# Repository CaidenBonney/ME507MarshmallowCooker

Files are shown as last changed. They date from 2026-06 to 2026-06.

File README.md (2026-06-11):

# ME507 Marshmallow Cooker

## Overview

The ME507 Marshmallow Cooker is an automated system designed to cook the perfect marshmallow for s'mores! The marshmallow cooker roasts the marshmallows to a desired temperature using sensor feedback and motorized positioning.

The system is based on an STM32F411 microcontroller and incorporates both contact and non-contact temperature sensing. The rotating mechanism (rotisserie) ensures an even cook while the vertical positioning system modulates the distance between the marshmallow and the heat source (demoing with a Sterno).

## Team Members

* Caiden Bonney
* Toby Sagi

## Hardware

### Sensors

* MLX90614 infrared temperature sensor
* MCP9600 thermocouple amplifier with Type T thermocouple
* Top and bottom Z-axis limit switches

### Actuators

* Pololu 5120 gearmotor with quadrature encoder and DRV8833 brushed DC motor driver
* DF Robot Fit0278 stepper motor with TMC2209 stepper motor driver

### Custom Electronics

* Custom PCB designed for STM32, sensor integration, and motor control.

## Firmware Architecture

The firmware is written primarily in C++ using STM32CubeIDE and STM32 HAL.

Major drivers include:

* Task_UI
* Task_Temps
* Task_R_Motor
* Task_Z_Motor
* MCP9600 thermocouple driver
* MLX90614 infrared temperature driver
* Encoder driver
* DRV8833 motor driver
* Rotational motor driver
* Z-axis limit switch driver
* Z-axis motor driver

## Documentation

Project documentation:

[ME507 Marshmallow Cooker Documentation](https://caidenbonney.github.io/ME507MarshmallowCooker/)

## Repository Structure

```text
ME507MarshmallowCooker
├── CAD
├── docs
├── Fusion
├── Marshmallow_Cooker
│   ├── Core
│   └── Drivers
├── Doxyfile
└── README
```

## Building the Project

1. Open `Marshmallow_Cooker` in STM32CubeIDE.
2. Build the project.
3. Flash the firmware to the STM32F411 target.
4. Open a serial terminal at 115200 baud for debugging output.

## License

This repository was created as part of the ME507 Mechatronics course at California Polytechnic State University.

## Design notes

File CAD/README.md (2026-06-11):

# CAD Files

This directory contains the mechanical CAD models, assemblies, and supporting design files used in the ME507 Marshmallow Cooker project.

## Contents

* Assembly file for the complete marshmallow cooker
* Individual part models
* Hardware: screws, nuts, etc.

## Software

The CAD models were created using SolidWorks.

## Purpose

These files document the mechanical design of the marshmallow cooker, including the rotating marshmallow assembly, vertical positioning mechanism, sensor mounting features, and overall system structure.

The CAD models were used for design iteration, interference checking, fabrication, and project documentation.

## Related Documentation

Additional renders and screenshots generated from these CAD models are included in the project documentation website.

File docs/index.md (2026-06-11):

@mainpage ME507 Marshmallow Cooker

# Project Overview

The ME507 Marshmallow Cooker is an automated marshmallow roasting system designed to cook the perfect marshmallow for s'mores. Using sensor feedback and motorized positioning, the system monitors temperature and automatically adjusts the marshmallow's position and orientation to achieve a consistent, repeatable roast.

<p align="center">
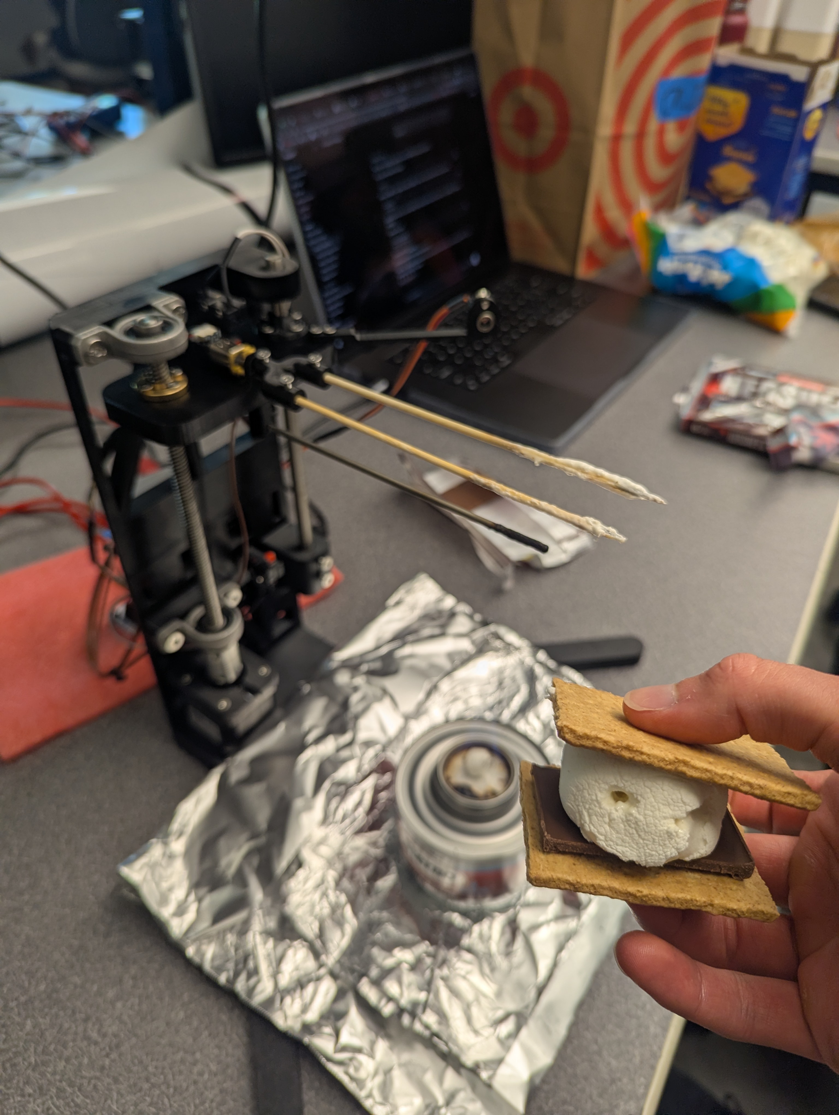
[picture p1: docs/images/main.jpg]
  
</p>

The system is based on an STM32F411 microcontroller and uses both infrared and thermocouple-based temperature measurements to monitor cooking conditions. A rotating mechanism (rotisserie) ensures an even cook, while a vertical positioning system adjusts the distance between the marshmallow and the heat source (demonstrated using a Sterno) to regulate roasting temperature. This combination of sensor feedback and motorized positioning allows the marshmallow to be cooked consistently to a desired temperature.

## Video Demonstration

[Click here to watch the Marshmallow Cooker in action!](https://cpslo-my.sharepoint.com/:v:/g/personal/clbonney_calpoly_edu/IQBmmSWm59pES4WM_rZA4jZBAax7FDM9BySxYHA97Abe1Qw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)

---

# Major Hardware

## BOM

Here is a link to our [Bill of Materials](https://cpslo-my.sharepoint.com/:x:/g/personal/clbonney_calpoly_edu/IQCO9qkZxfa1SrjVX5YEZTvCAYXNW5hFe5g4LbXm4rrSlMY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) (does not include CAD components)

## Rotating Motor Assembly

The rotating axis uses a Pololu 5120 gearmotor with integrated quadrature encoder. The 297.92:1, 45 rpm max motor provides slow, yet steady rotation of the marshmallow. A DRV8833 motor driver at 5V allows bidirectional PWM control from the STM32 microcontroller. A simple software driver was implemented to abstract direction control and PWM duty cycle commands.

<p align="center">
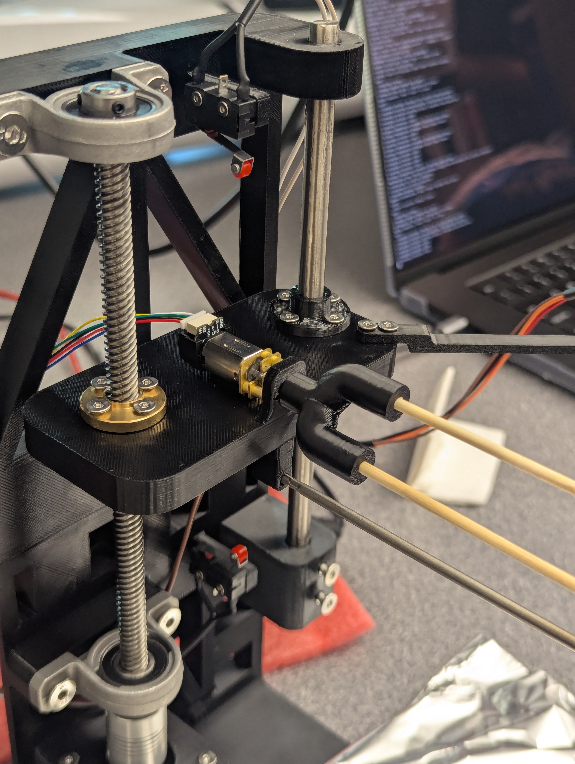
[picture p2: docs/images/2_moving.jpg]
  
</p>

The 12 CPR quadrature encoder provides position feedback that allows the software to estimate angular position and rotational velocity. Hardware timers count the encoder ticks, measuring the angular displacement of the motor.

<p align="center">
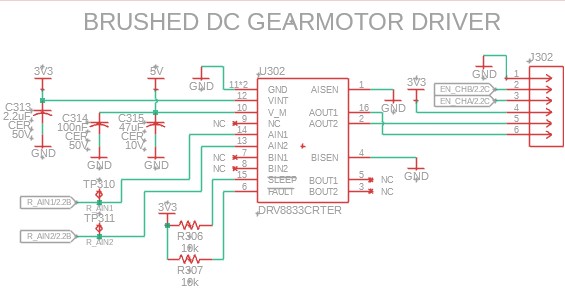
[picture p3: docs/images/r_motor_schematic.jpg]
  
</p>

## Vertical Motion System

<p align="center">
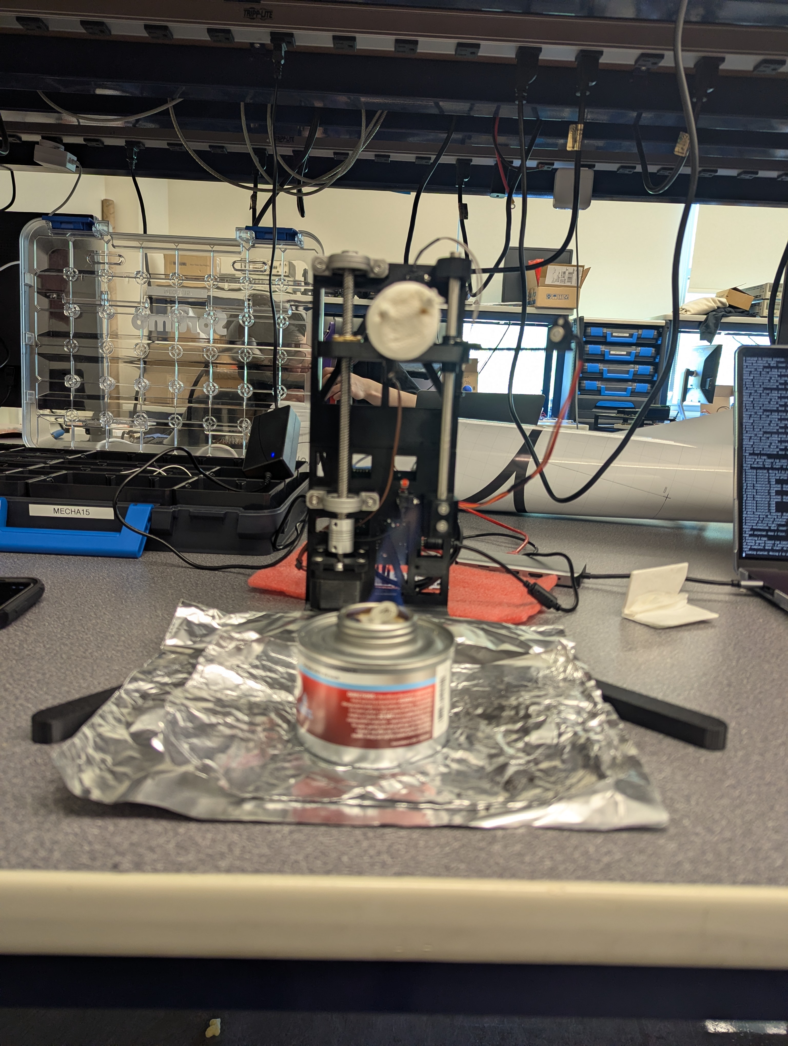
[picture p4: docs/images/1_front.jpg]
  
</p>

The distance between the marshmallow and the heat source is adjusted by a lead screw system powered by a stepper motor, DFRobot FIT0278 stepper motor. The motor is controlled by a TMC2209 driver at 12V. The FIT0278 has 200 steps per revolution, and the motor driver is configured for 8 microsteps per step. The result is smooth, fine control of the height of the marshmallow above the fire.

The TMC2209 stepper motor driver schematic is shown below. We installed a potentiometer into the resistor divider for VREF, so we could tune the maximum current sent to the stepper motor. Our VREF range is roughly 0.8V to 2.5V. Additionally, we selected the shunt resistor value used by the driver to sense motor current.

<p align="center">
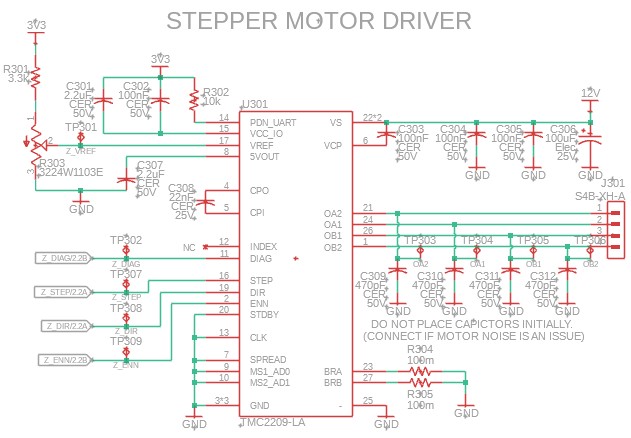
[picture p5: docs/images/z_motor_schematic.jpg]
  
</p>

Top and bottom limit switches are used to prevent the mechanism from exceeding its allowable travel range. The limit switches are wired normally closed (NC), with internal pull up resistors configured on the STM32. When a limit switch is pressed, the ground connection is broken, and the pin is forced high by the pull up resistor. When a limit switch is pressed, the ground connection is broken and the pin is forced high by the pull-up resistor. This fail-safe design causes a disconnected cable, damaged switch, or wiring failure to be detected as an active limit condition. This fail-safe behavior causes a disconnected or damaged switch to be detected as a triggered limit condition.

## Temperature Sensors

<p align="center">
  
</p>

### MLX90614 Infrared Temperature Sensor

The MLX90614 provides non-contact temperature measurements of the marshmallow surface. This allows surface temperature to be monitored without physically touching the marshmallow. When the marshmallow's surface reaches a set temperature, the cook is done.

The MLX90614 is an integrated IR temperature camera and I2C device. This makes implementation very simple as it does not require an amplifier or driver. The IR temperature sensor itself communicates with the STM32 via I2C CLK and SDA.

### MCP9600 Thermocouple Amplifier

The MCP9600 thermocouple amplifier interfaces with a Type T thermocouple to provide direct hot-junction temperature measurements of the flame. The flame temperature is used in our control loop to adjust the height of the marshmallow.

The MCP9600 is also an I2C device. It has a configurable address pin, which is grounded, setting the address to 0x60. The hot junction temperature is read via the hardware I2C bus as the IR temperature sensor.

## Custom PCB

<p align="center">
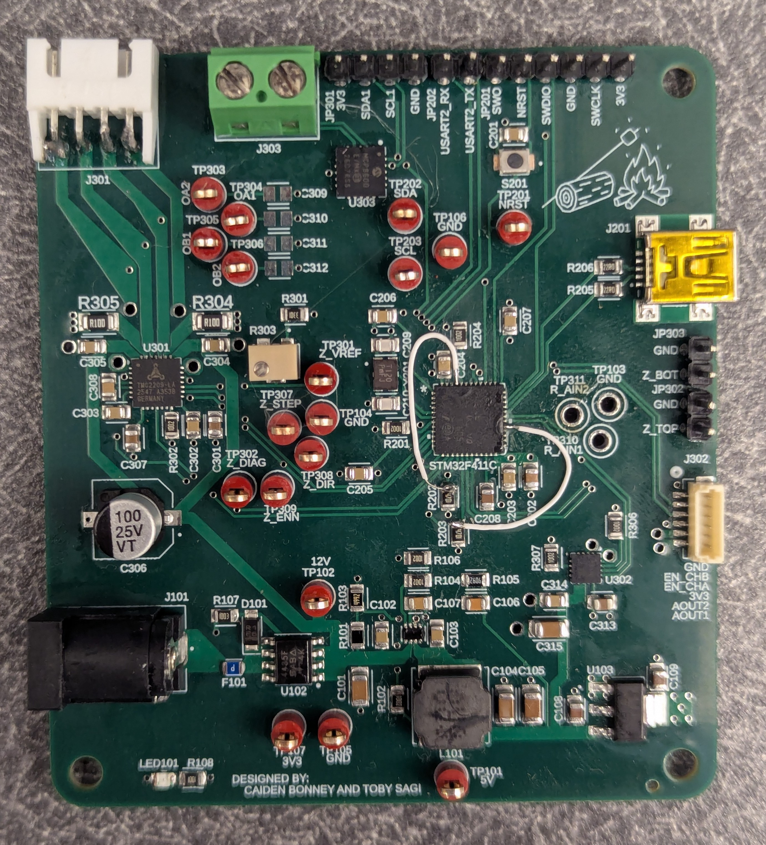
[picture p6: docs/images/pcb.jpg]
  
</p>

A custom PCB was designed to integrate all hardware components:

* STM32F411 microcontroller
* MCP9600 thermocouple amplifier
* MLX90614 infrared temperature sensor
* DRV8833 motor driver
* \ref REncoderDriver "Encoder" inputs
* TMC2209 stepper motor driver interface
* \ref ZLimitSwitches "Limit switch" inputs

<p align="center">
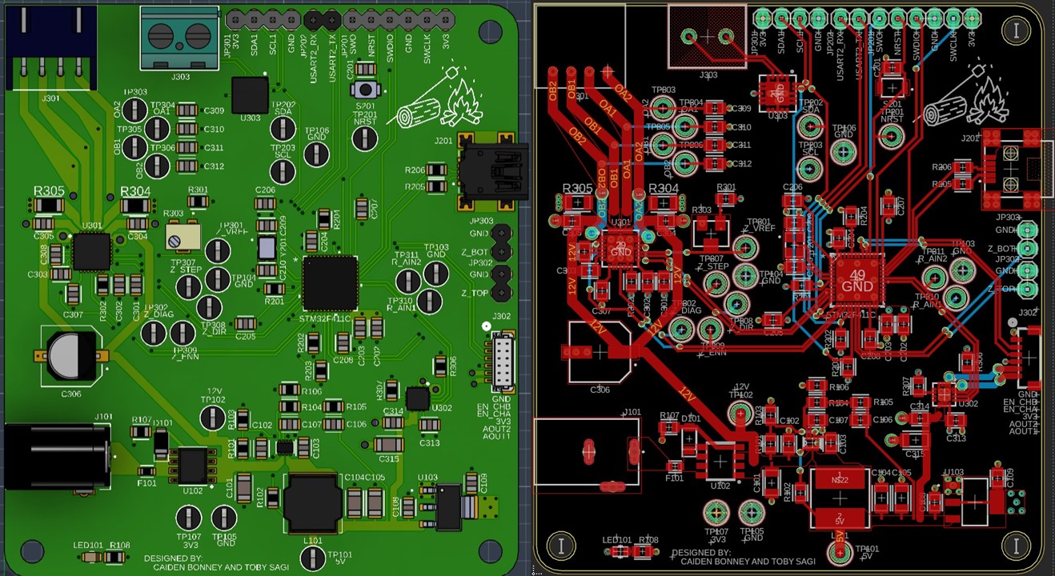
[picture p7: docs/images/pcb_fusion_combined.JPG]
  
</p>

The PCB simplifies wiring and provides a compact platform for system integration. Our board begins with the 12 VDC barrel plug, designed for an external wall AC to DC converter. The 12 VIN goes through a fuse (MFU0805FF03000P500) and p-fet reverse polarity circuit (SI4435FDY-T1-GE3). Then, a high efficiency switching buck regulator (MP2338GTL-Z) drops the voltage to 5V for the rotating motor. Finally, a linear dropout regulator (LDL1117S33R) reduces the voltage to 3.3V, our digital logic level (VDD).

Key PCB Design Choices:
* Internal planes for GND and VDD
* Surface mounted components only on the top layer
* Reducing high power trace lengths
* Potentiometer for TMC2209 VREF
* Pads for optional stepper motor phase decoupling capacitors

Due to the project's tight timeline, we found multiple issues with our PCB that we would fix if given time and money for another board revision.

Issues We Encountered:
* Wrong pins for I2C
  * Problem: We mixed up ports A and B in the schematic. Connected traces to PA6 & PA7 instead of PB6 & PB7 for I2C1.
  * Solution: Soldered 32 AWG Kynar wire to jump pins PA8 & PB8 (I2C3) to the pull up resistor and rest of the I2C pcb wiring.

<p align="center">
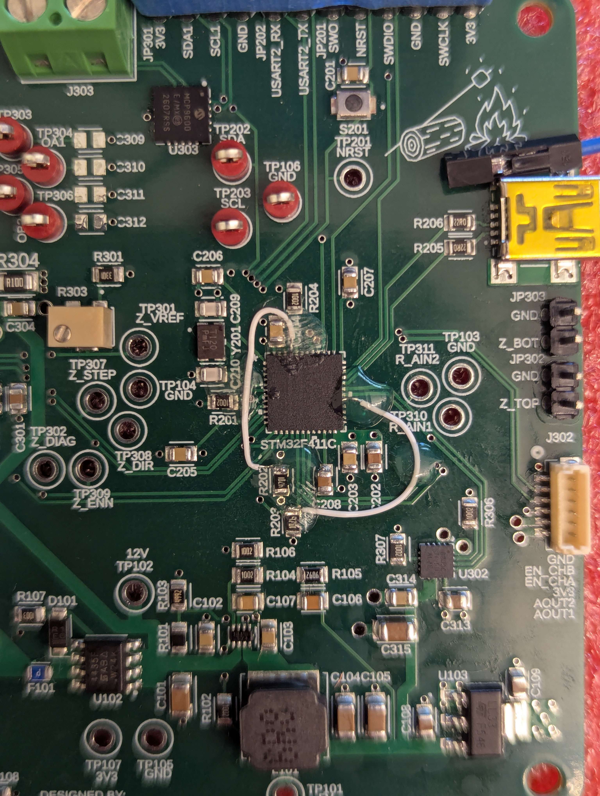
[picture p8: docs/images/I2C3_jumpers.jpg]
  
</p>

* Switching regulator placed 180 degrees
  * Problem: When purchasing the PCB we probably missed seeing that the switching regulator was placed 180 degrees incorrectly.
  * Solution: Used hot air soldering gun to remove the switching regulator, rotate it 180 degrees, and place it back on the pads.

<p align="center">
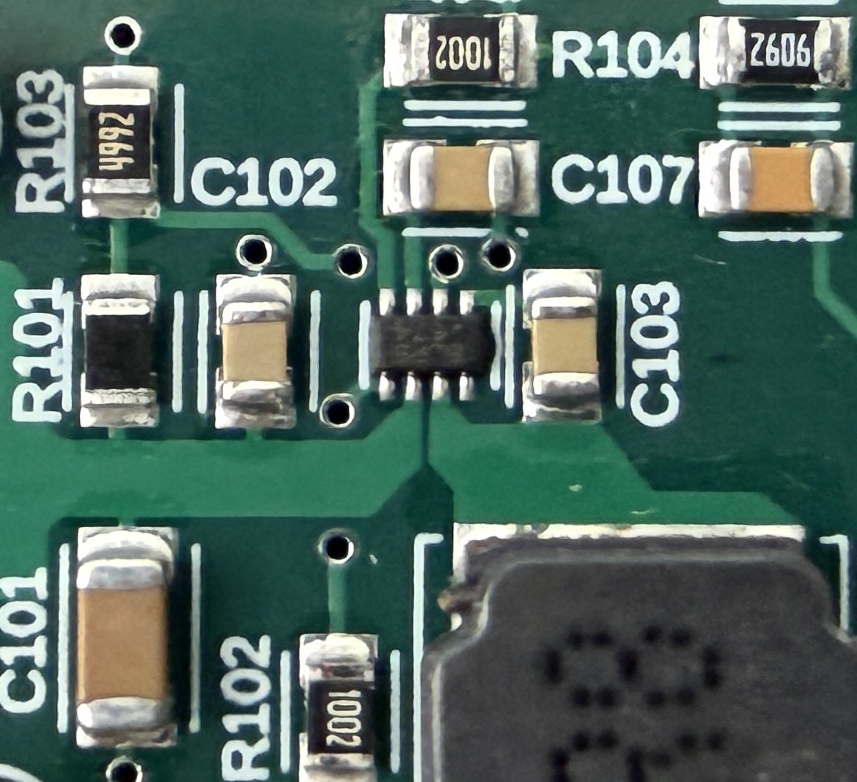
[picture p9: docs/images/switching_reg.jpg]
  
</p>

* Thru holes for stepper motor JST connector too small
  * Problem: We did not verify the recommended hole size of the downloaded connector footprint. Result was vias were too small for the thru hole pins of the JST-XH connector.
  * Solution: Attempted to expand the vias, but lifted the pads and some traces. Cut back the lifted traces, chipped off the solder mask to expose the copper, soldered the connector's pins onto the copper traces. Super glued the connector's body onto the board. Never unplugging the connector on the board side.

<p align="center">
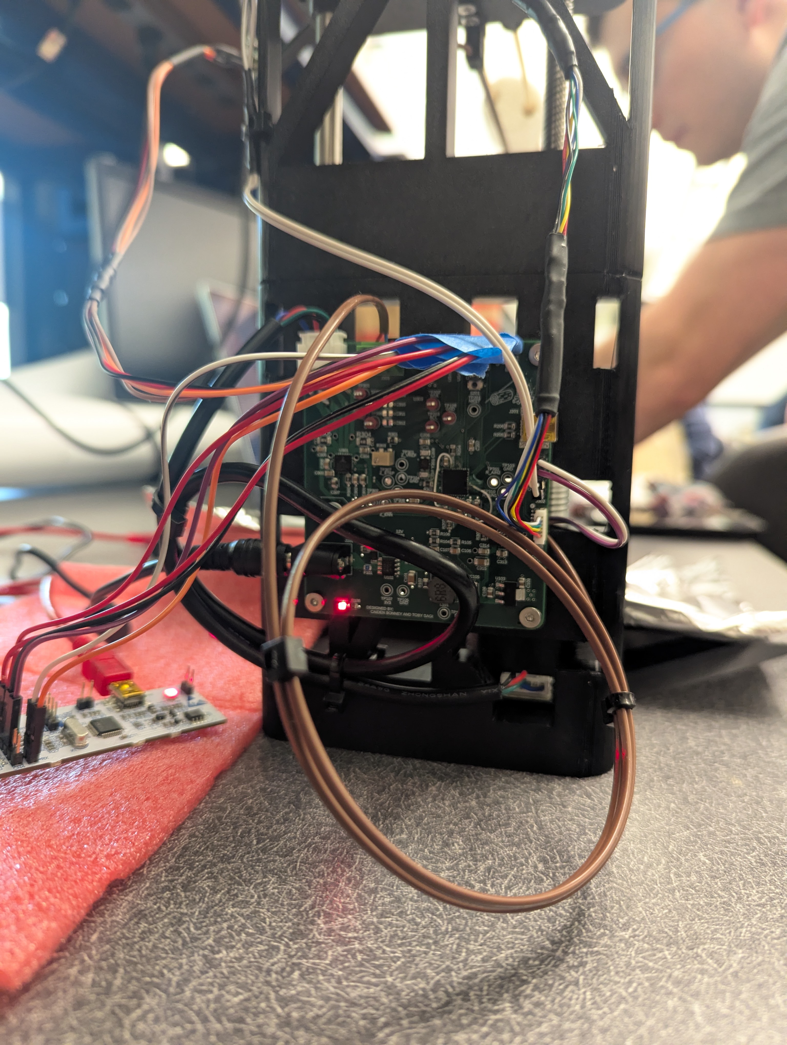
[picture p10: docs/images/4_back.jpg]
  
</p>

---

# CAD

The GitHub repository contains CAD for the marshmallow cooker. This includes a main assembly file, individual part models, and hardware components such as screws and nuts. All custom components were 3D printed from PETG using a Bambu Lab P1S printer. A combination of nyloc nuts, standard nuts, and 3D-printed threaded pilot holes was used to assemble the system. Most parts were designed with additive manufacturing in mind. Where possible, support material was minimized, and "speed holes" were added to reduce print time and material usage.

The vertical gantry consists of a lead screw driven by the stepper motor and a smooth guide shaft. Because only two points define the sliding platform's plane, the mechanism can rock under the weight of the motor, thermocouple, and marshmallow. Additionally, the gantry can bind during motion. We mitigated binding by providing a small clearance fit around the guide shaft, lubricating the shaft, and commanding the stepper motor to move at least one-half revolution per motion command.

The thermocouple and marshmallow mount underwent several design iterations throughout the project. Initially, the thermocouple was attached directly to the rotating motor assembly, but the thermocouple wire wrapped around the shaft and became tangled. We first mitigated this issue by rotating 360 degrees in one direction and then 360 degrees in the opposite direction. Later, we redesigned the mount so that two skewers penetrate the marshmallow. This ensures that the marshmallow rotates with the motor while separating it from the thermocouple. Since the thermocouple no longer rotates, the wire cannot wrap around the shaft, and the marshmallow does not interfere with the temperature measurement.

<p align="center">
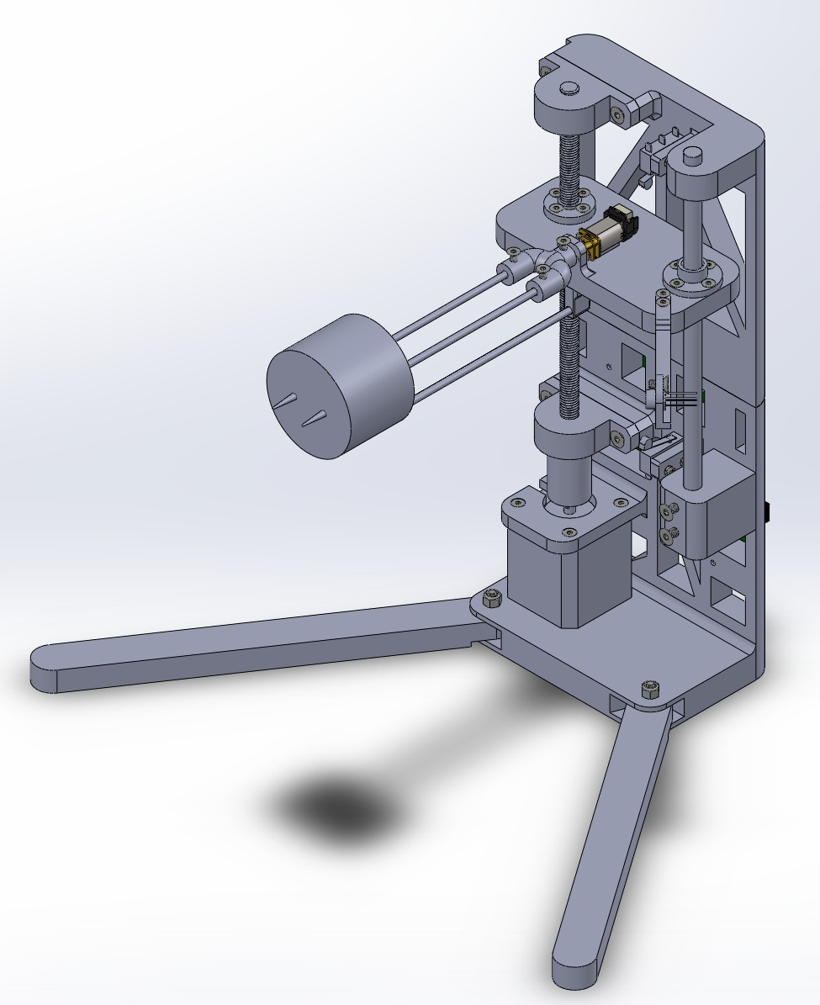
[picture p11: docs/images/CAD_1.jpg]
  
</p>

<p align="center">
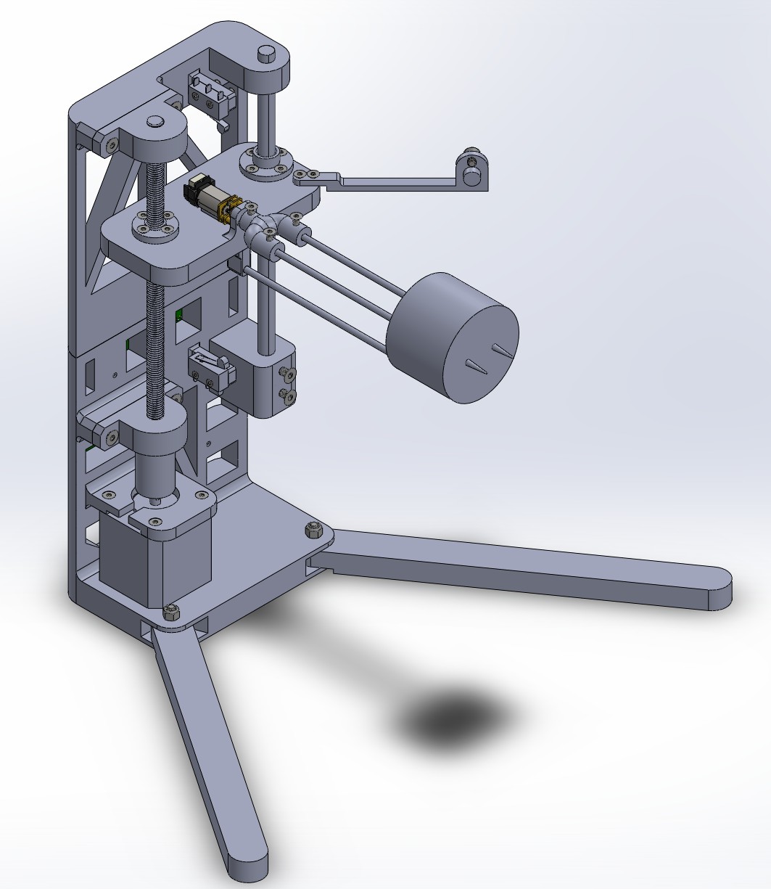
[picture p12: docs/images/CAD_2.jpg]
  
</p>

<p align="center">
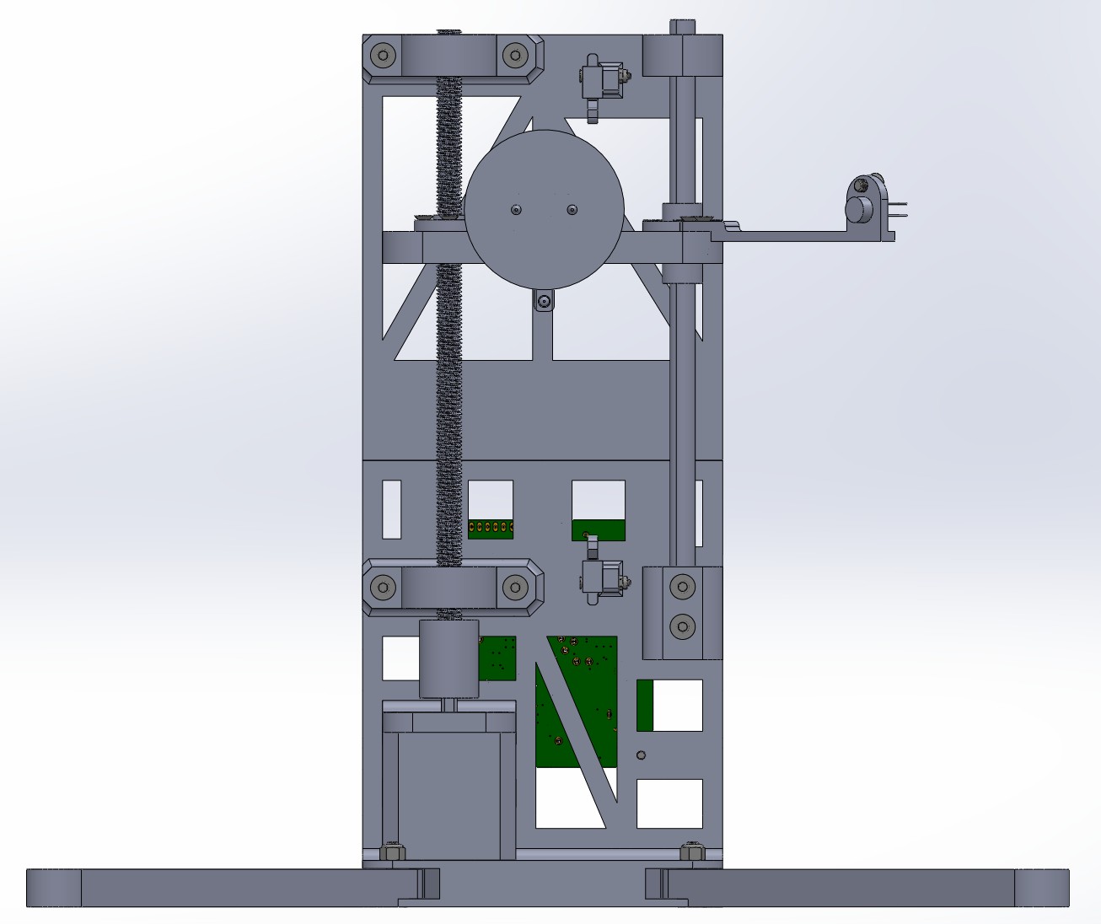
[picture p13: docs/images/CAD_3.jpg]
  
</p>

<p align="center">
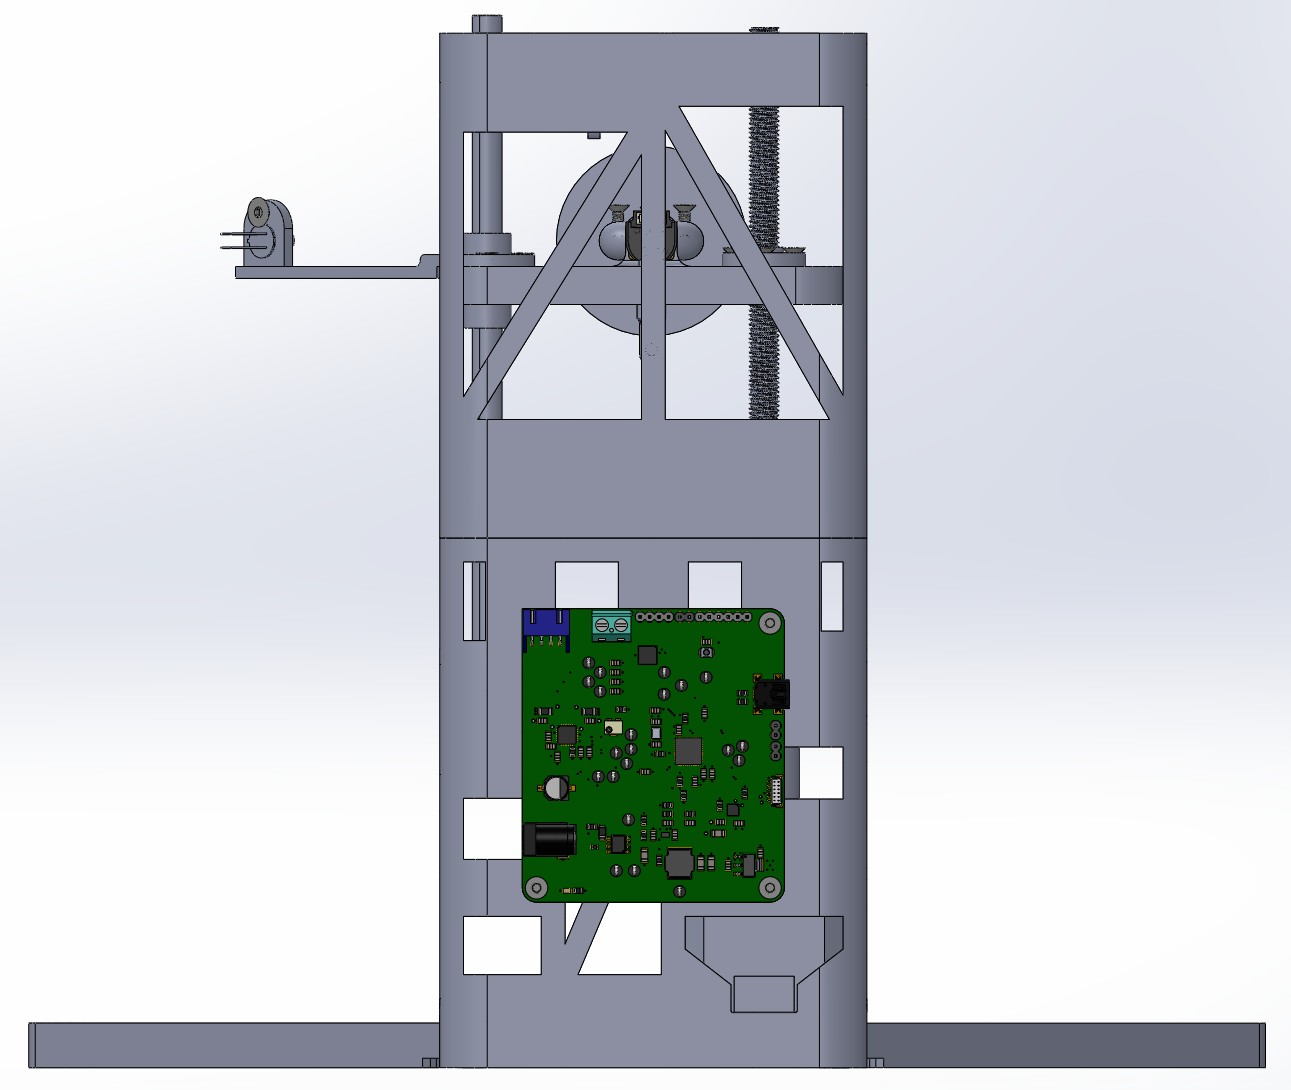
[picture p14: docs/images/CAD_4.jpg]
  
</p>

---

# Software Architecture

The firmware is written in C++ using STM32CubeIDE and STM32 HAL.

Major software modules include:

* DRV8833 motor driver
* MCP9600 thermocouple driver
* MLX90614 infrared sensor driver
* \ref REncoderDriver "Encoder" driver
* \ref RMotorDriver "Rotational motor" driver
* \ref ZMotorDriver "Z-axis motor" driver
* \ref ZLimitSwitches "Z-axis limit switch" driver

Hardware-specific functionality is encapsulated within dedicated driver classes, allowing higher-level control logic to remain independent of hardware implementation details.

---

# Main Control Structure

The application uses a cooperative task structure built around the shared \ref Task interface. After STM32Cube-generated initialization configures GPIO, USART2, I2C3, TIM1 PWM, TIM3 encoder mode, and USB device support, `main()` repeatedly calls the application tasks in a fixed order:

* \ref TaskUI "TaskUI" parses any completed user command.
* \ref TaskTemps "TaskTemps" periodically updates the thermocouple and IR temperature readings.
* \ref TaskCooker "TaskCooker" consumes commands, checks sensor data, and issues high-level motion requests.
* \ref TaskRMotor "TaskRMotor" updates the rotisserie motor.
* \ref TaskZMotor "TaskZMotor" updates the vertical stepper motor.

This ordering lets new command and temperature data be processed before the motor tasks act on the latest cooker decisions. The tasks are written as small non-blocking state machines using `HAL_GetTick()` timing instead of long blocking delays. The temperature and Z-control tasks run their scheduled logic every 500 ms, while the R motor task updates every 10 ms so encoder-driven rotation remains responsive.

---

# User Interface

The firmware provides a serial command-line interface through \ref TaskUI "TaskUI". USART2 is configured for 115200 baud, 8 data bits, no parity, and 1 stop bit. The UI task receives one byte at a time with `HAL_UART_Receive_IT()`, stores characters in a small interrupt-to-task queue, echoes printable input, supports backspace, and parses commands when the user presses Enter.

The user-facing cook sequence is coordinated by \ref TaskCooker "TaskCooker". On startup it waits for the `home` command, then commands \ref TaskZMotor "TaskZMotor" to home upward until the top limit switch defines Z = 0. Once homed, the cooker enters `ReadyToCook` and accepts `start`. Starting a cook moves Z to the initial cooking height, enables flame-temperature control, and then starts the R-axis rotisserie once Z reaches active control. A normal stop, completed cook, or bottom-limit condition commands the R motor back to its initial rotation and moves Z to the removal height. Faults and emergency stops immediately stop both motor tasks and require `reset` followed by another `home` before cooking again.

Supported commands are:

* `home` - home the Z axis against the top limit switch and prepare the cooker.
* `start` - begin a cooking cycle after Z has been homed.
* `stop` - perform a normal stop by returning R to zero and moving Z to removal height.
* `estop` - immediately enter the fault state and stop both motors.
* `reset` - clear a `Fault` or `Done` state and require another home cycle.
* `status` - print one status line.
* `status <ms>` - stream status lines for the requested duration in milliseconds.
* `rotate` - toggle manual R-axis cooking rotation while ready.
* `piddebug on` / `piddebug off` - enable or disable Z PID debug messages.
* `- <steps>` - jog Z downward by the requested number of steps.
* `= <steps>` - jog Z upward by the requested number of steps.

If no step count is supplied for `-` or `=`, the default jog distance is 100 steps. Status output reports the cooker state, Z task state, R task state, Z position, top and bottom limit switch states, thermocouple hot-junction temperature, and IR object temperature. `print_str()` sends firmware messages over USART2 and also mirrors them to USB CDC when USB support is present in the build.

---

# Control Loop

The cooking loop uses two temperature measurements for two different jobs. \ref TaskTemps "TaskTemps" polls the MCP9600 thermocouple amplifier and MLX90614 IR sensor over I2C3 every 500 ms. The thermocouple hot-junction reading is treated as the flame temperature used by Z-axis control, while the IR object reading is used as the marshmallow done-temperature measurement.

When `start` is accepted, \ref TaskCooker "TaskCooker" commands \ref TaskZMotor "TaskZMotor" to move from the homed top reference to the starting cook position at -11000 steps. Once that move finishes, Z enters `ControllingFlameTemp`. The cooker then starts the R-axis cooking motion, which alternates +360 degree and -360 degree moves so the marshmallow rotates without winding wires indefinitely. Since writing code, the mechanical system has changed and this is no longer necessary. The motor could spin in one direction indefinitely.

The Z-axis PID loop runs every 500 ms with a target flame temperature of 240.00 F. Temperatures are stored as fixed-point Fahrenheit values multiplied by 100. The PID error is:

```text
error = target flame temperature - measured flame temperature
```

A positive error means the measured flame temperature is too cold, so the Z target is moved downward toward the flame. A negative error means the flame is too hot, so the Z target is moved upward. The default gains are `Kp = 1.0`, `Ki = 0.02`, and `Kd = 0.10`. Each PID update is clamped to +/-750 steps with a +/-100 step deadband, and the integral term is limited to reduce wind-up. Software limits prevent commands above the home position or below the -16000 step lower cook limit.

Cooking completes when the IR object temperature reaches 250.00 F continuously for 1.5 seconds. At that point the cooker begins a normal stop: the R motor returns to encoder zero and Z moves to the -500 step removal height. If a motor fault or emergency stop occurs, the cooker enters `Fault`, stops motion, and waits for a reset sequence.

## How to Improve the Control Loop

The thermocouple has a very large time constant. This means it takes a long time for the hot-junction temperature to respond to changes in the surrounding air temperature. This is undesirable because the Z-axis height control loop is closed using a sensor that is effectively reporting old data. We mitigated this issue by tuning relatively low PID gains. As a result, the vertical motion responds slowly, giving the thermocouple more time to approach the true temperature before additional control actions are taken. This behavior could be improved by using a thermocouple with lower thermal mass and, therefore, a smaller time constant.

---

# Repository Structure

```text
ME507MarshmallowCooker
├── CAD
├── docs
├── Fusion
├── Marshmallow_Cooker
│   ├── Core
│   └── Drivers
├── Doxyfile
└── README
```

## Repository

GitHub Repository:

[Link back to ME507MarshmallowCooker GitHub Repository](https://github.com/CaidenBonney/ME507MarshmallowCooker)

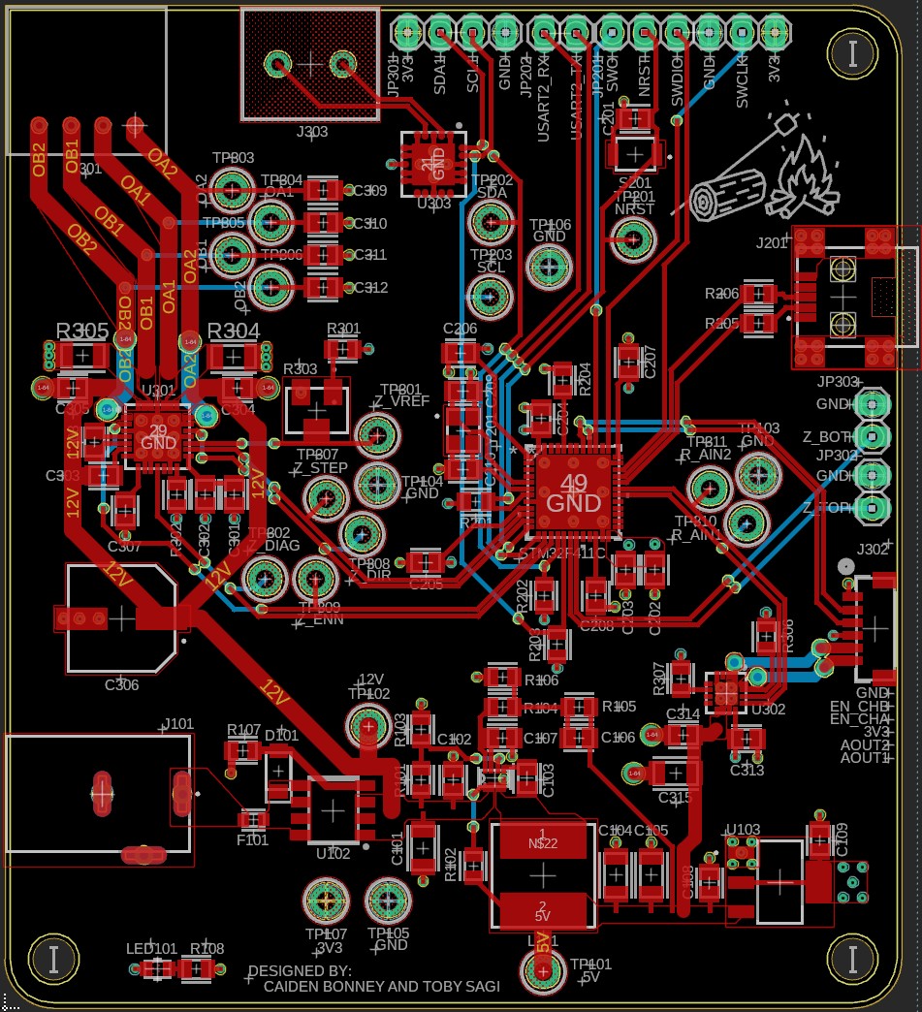
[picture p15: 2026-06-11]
docs/images/pcb_schematic.jpg

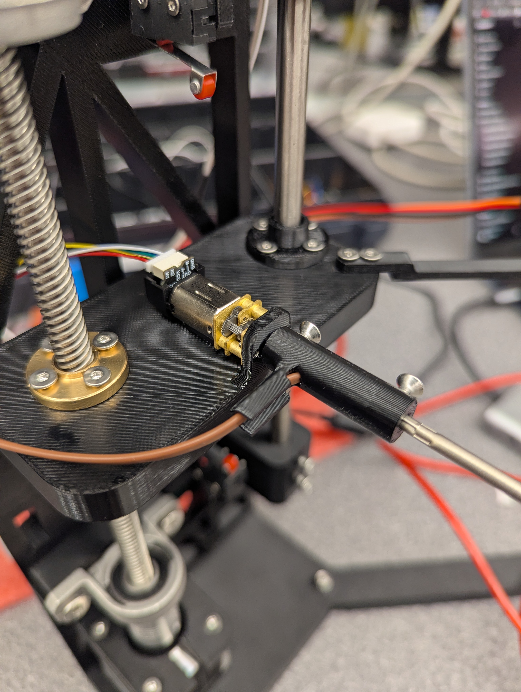
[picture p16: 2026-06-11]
docs/images/r_motor.jpg

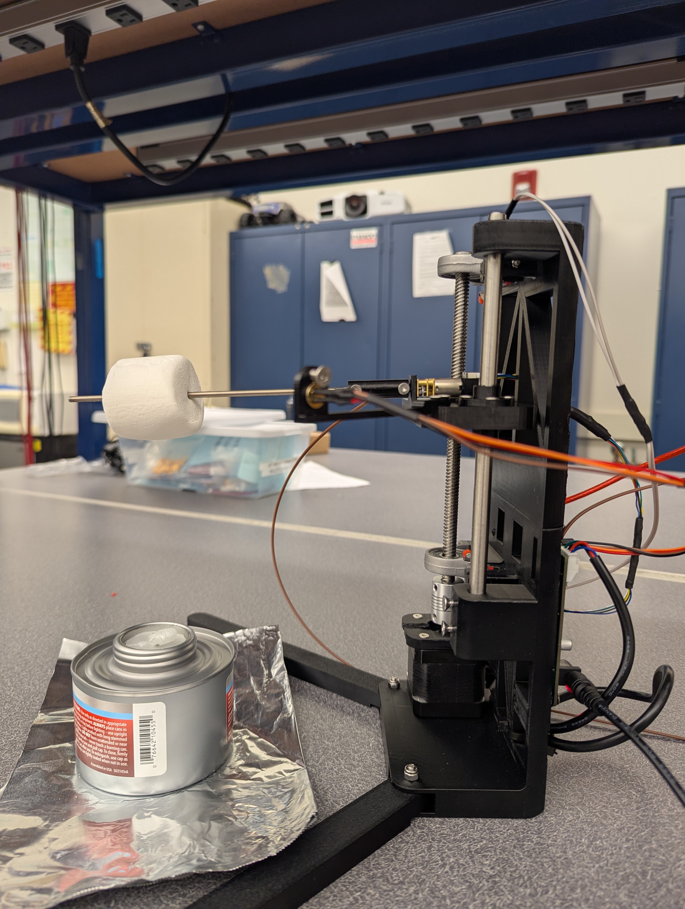
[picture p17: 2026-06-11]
docs/images/side_view.jpg

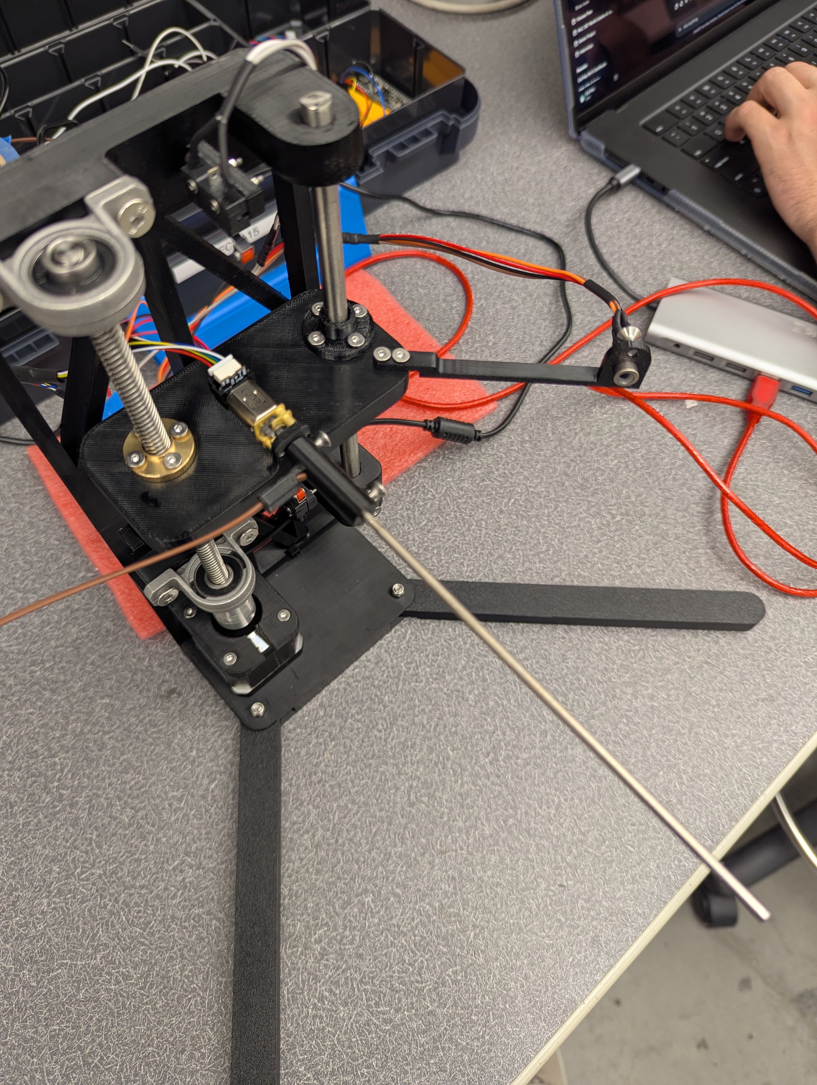
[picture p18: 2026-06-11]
docs/images/thermocouple.jpg

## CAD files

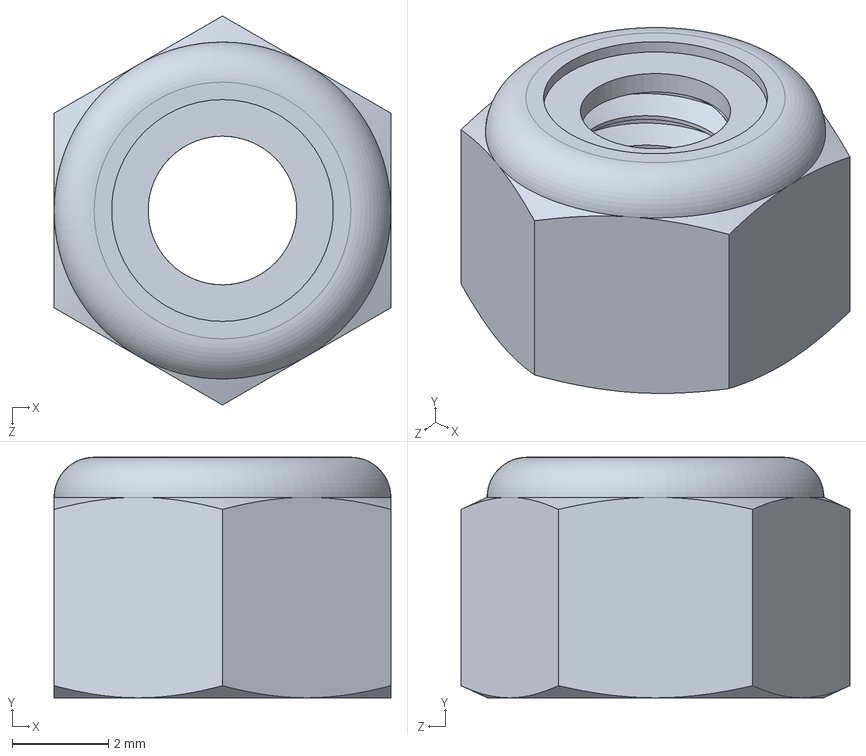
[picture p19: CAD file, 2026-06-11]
CAD/Hardware/M4-nylock.SLDPRT
7.00 x 5.00 x 8.08 mm

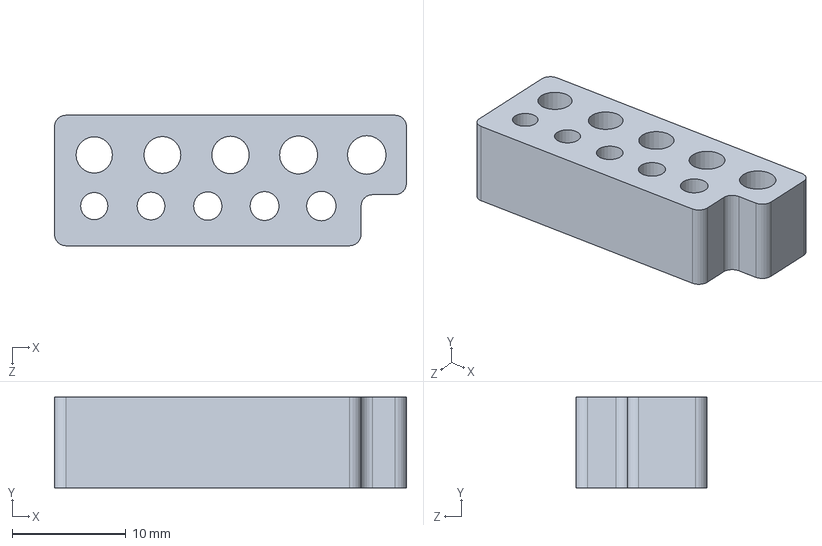
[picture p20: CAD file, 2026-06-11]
CAD/Hole Sizing/Thread Test.SLDPRT
31.0 x 8.00 x 11.5 mm

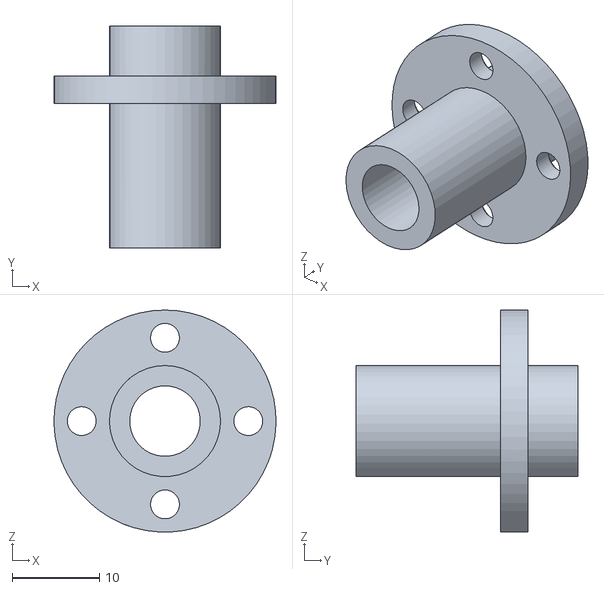
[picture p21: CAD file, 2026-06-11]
CAD/STL Files/6-10-26/Guide Slider 0.3175in.STL
25.4 x 25.4 x 25.4

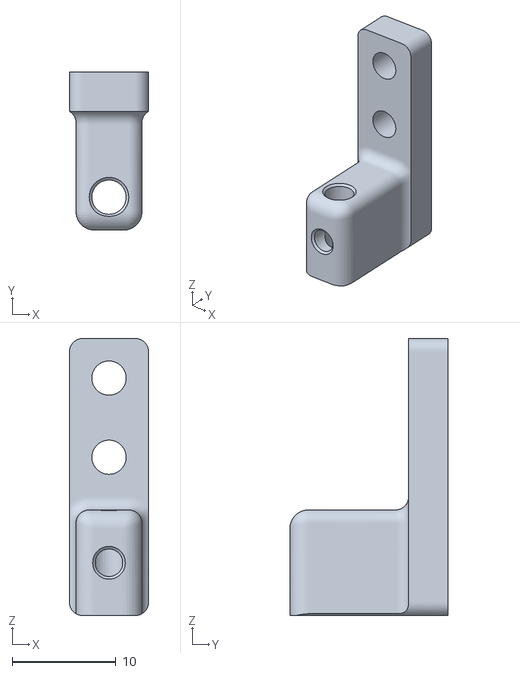
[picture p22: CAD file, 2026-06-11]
CAD/STL Files/6-11-26/TC Mount.STL
7.62 x 15.2 x 26.7

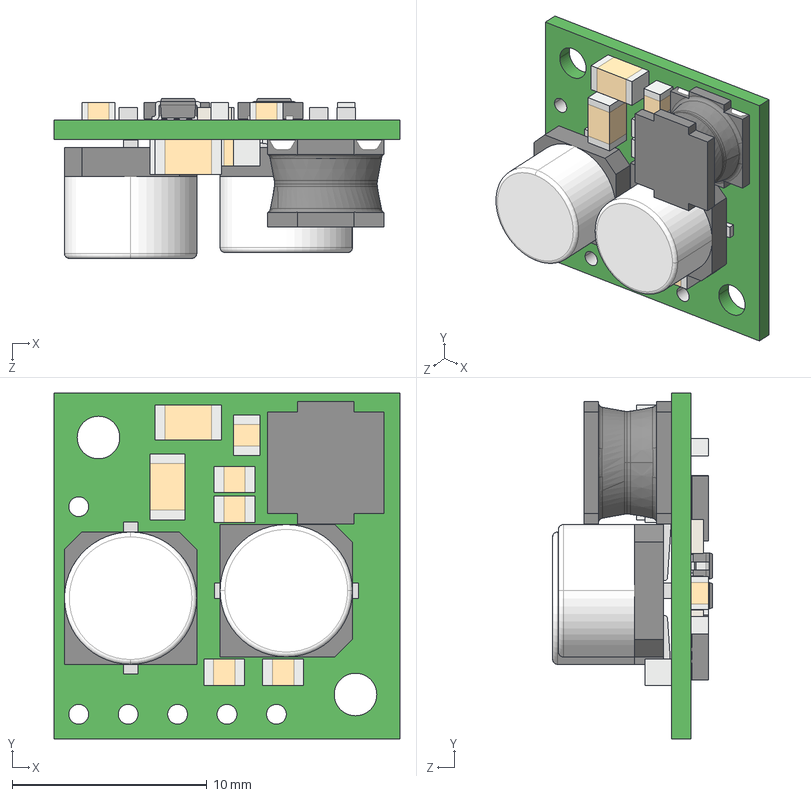
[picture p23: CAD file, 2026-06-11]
CAD/STL Files/d24v22fx-step-down-voltage-regulator.step
17.8 x 17.8 x 8.22 mm

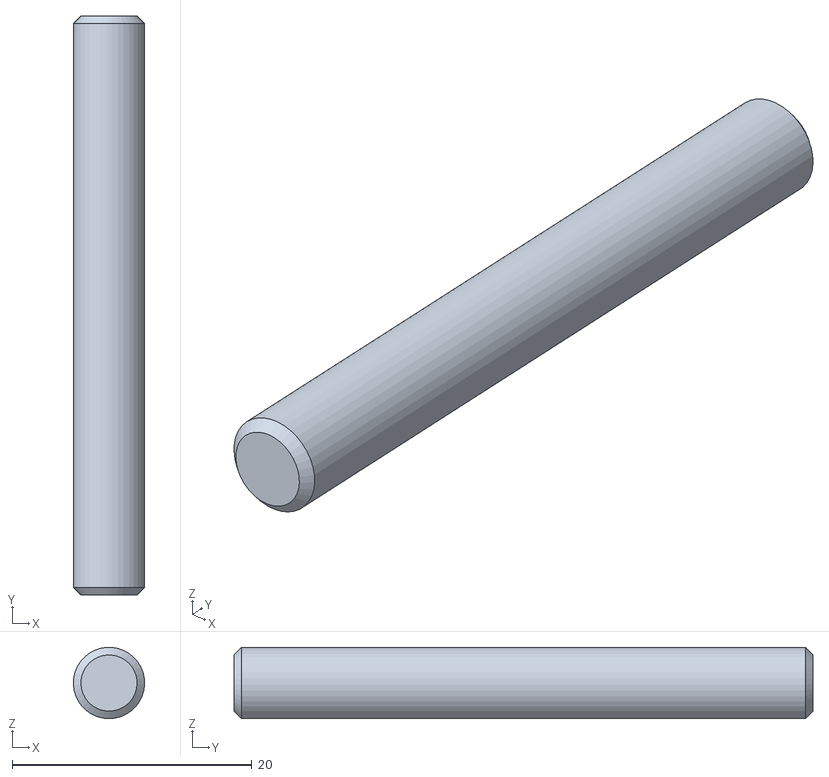
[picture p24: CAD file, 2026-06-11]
CAD/STL Files/Parts/Dowel Need 3.STL
5.94 x 48.3 x 5.95

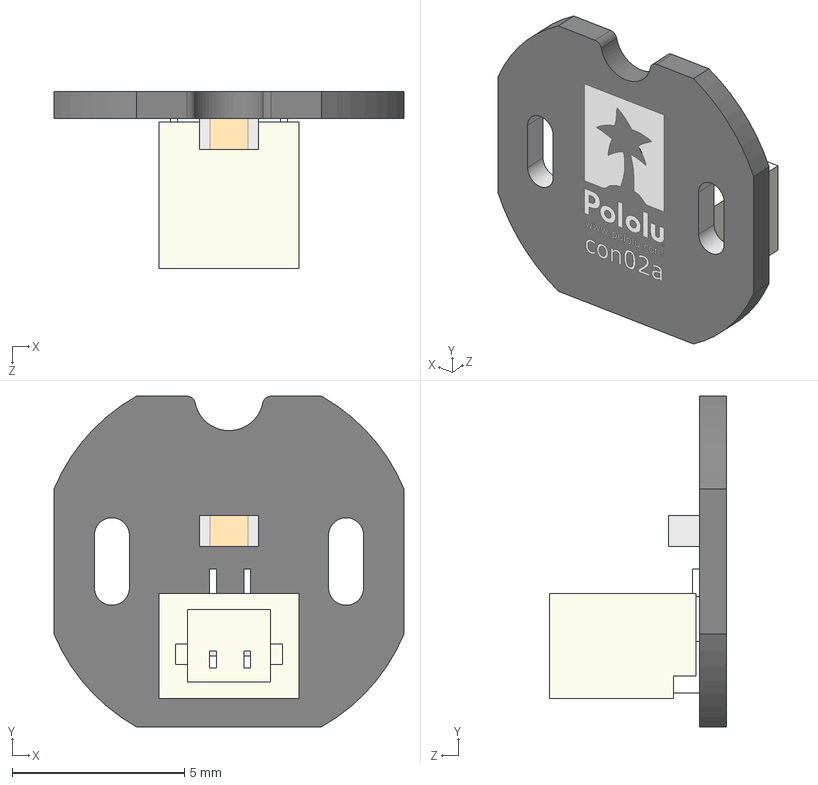
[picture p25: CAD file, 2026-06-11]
CAD/STL Files/Pololu Micro Metal Gearmotor 3D (STEP) Models/Accessories/jst-sh-style-connector-board-for-micro-metal - Copy.step
10.2 x 9.60 x 5.14 mm

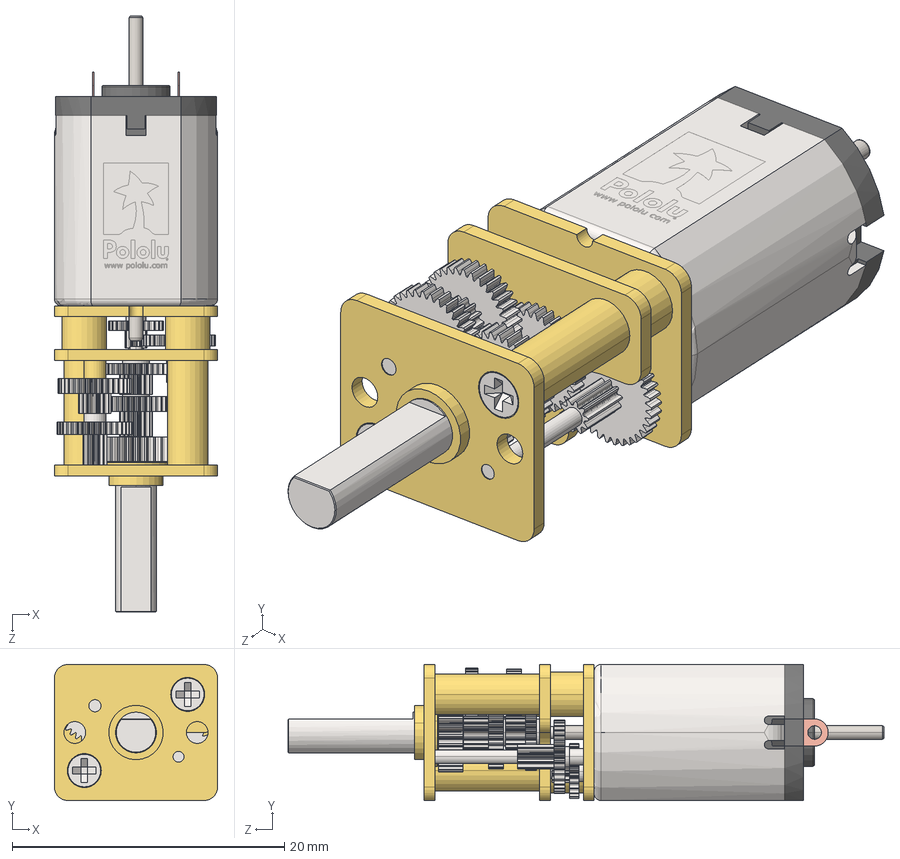
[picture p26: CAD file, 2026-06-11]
CAD/STL Files/Pololu Micro Metal Gearmotor 3D (STEP) Models/Encoder-Compatible (Extended Motor Shaft)/mmgm-1000-cb-ext-shaft.step
12.0 x 10.0 x 43.8 mm

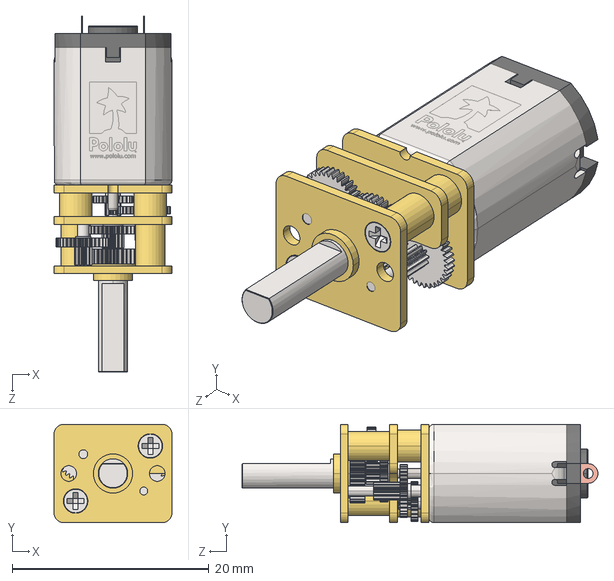
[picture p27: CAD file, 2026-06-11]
CAD/STL Files/Pololu Micro Metal Gearmotor 3D (STEP) Models/No Encoder/mmgm-cb.step
12.0 x 10.0 x 36.2 mm

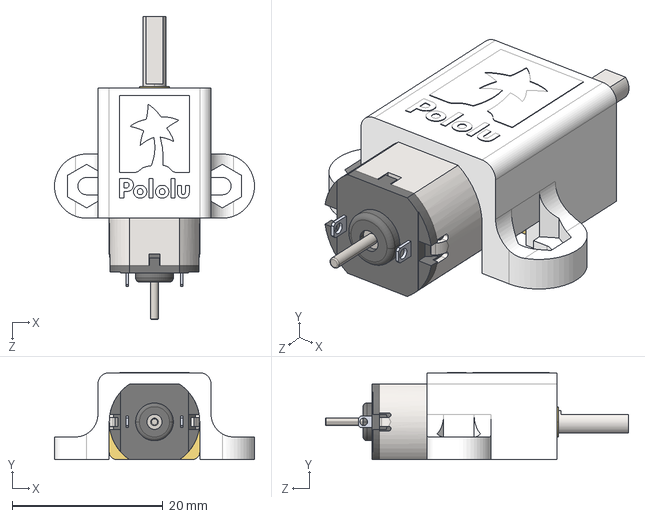
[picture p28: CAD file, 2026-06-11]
CAD/STL Files/Pololu Micro Metal Gearmotor 3D (STEP) Models/With Bracket/mmgm-pm-ext-shaft-with-1089-ext-bracket.step
26.5 x 11.6 x 40.2 mm

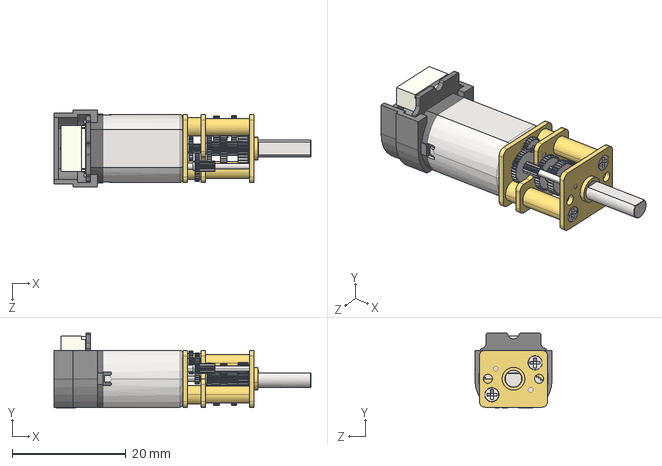
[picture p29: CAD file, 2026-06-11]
CAD/STL Files/Pololu Micro Metal Gearmotor 3D (STEP) Models/With Encoder, Back Connector/mmgm-1000-pm-enc-back-con.step
45.1 x 13.1 x 13.6 mm

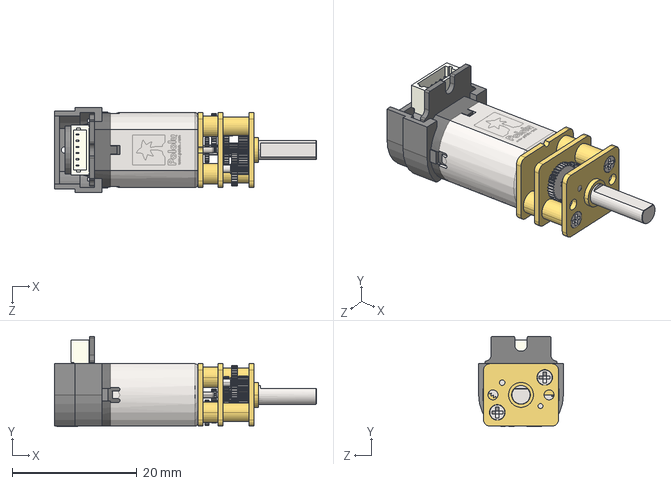
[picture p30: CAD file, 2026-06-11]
CAD/STL Files/Pololu Micro Metal Gearmotor 3D (STEP) Models/With Encoder, Side Connector/mmgm-cb-enc-side-con.step
42.0 x 14.5 x 13.6 mm

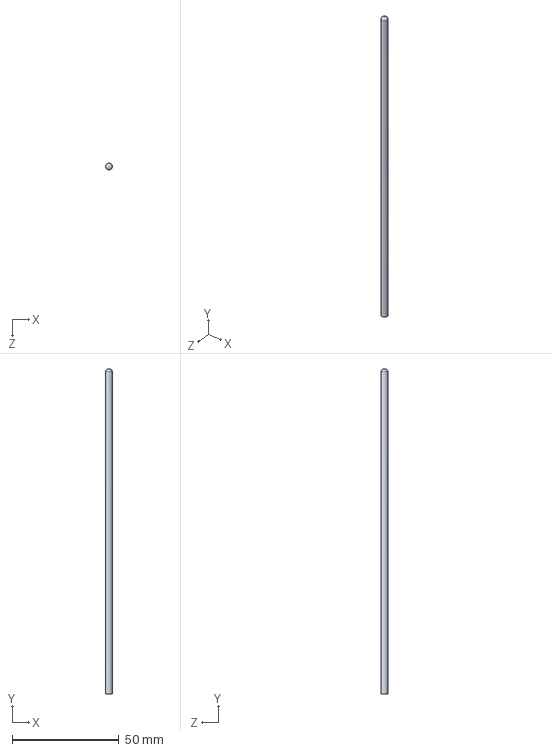
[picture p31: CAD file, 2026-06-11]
CAD/Thermocouple.SLDPRT
3.17 x 152.4 x 3.17 mm

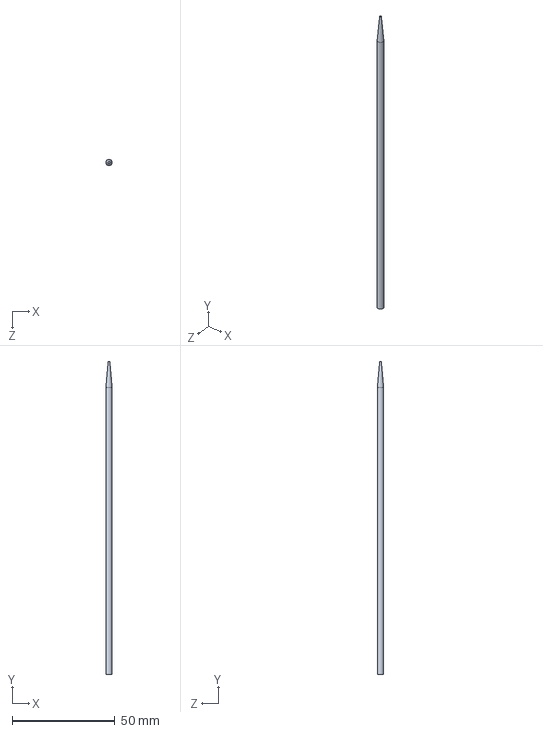
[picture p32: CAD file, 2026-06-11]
CAD/Skewer.SLDPRT
3.10 x 152.4 x 3.10 mm

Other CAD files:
CAD/PCB.SLDASM
CAD/STL Files/2100-0008-0200.STEP
CAD/STL Files/6-10-26/Guide Slider 0.3155in.STL
CAD/STL Files/6-11-26/Coupler v3.STL
CAD/2100-0008-0200.SLDPRT
CAD/5mm-to-8mm-Connector.SLDPRT
CAD/Base-Top.SLDPRT
CAD/Base.SLDPRT
CAD/Coupler.SLDPRT
CAD/Dowel.SLDPRT
CAD/Guide Slider.SLDPRT
CAD/Hardware/M1.6-4.SLDPRT
CAD/Hardware/M1.6-6.SLDPRT
CAD/Hardware/M2-16.SLDPRT
CAD/Hardware/M2-20.SLDPRT
CAD/Hardware/M2-8.SLDPRT
CAD/Hardware/M2-nylock.SLDPRT
CAD/Hardware/M3-12.SLDPRT
CAD/Hardware/M3-20.SLDPRT
CAD/Hardware/M3-8.SLDPRT
CAD/Hardware/M4-12.SLDPRT
CAD/Hardware/M4-20.SLDPRT
CAD/Hardware/M4-8.SLDPRT
CAD/Hole Sizing/Thread Test - Copy - Copy.SLDPRT
CAD/Hole Sizing/Thread Test - Copy.SLDPRT
CAD/Hybrid-Stepper-Motor.SLDPRT
CAD/IR Mount.SLDPRT
CAD/Lead-Screw-Nut.SLDPRT
CAD/Lead-Screw-Shaft.SLDPRT
CAD/Leg.SLDPRT
CAD/MLX90614.SLDPRT
CAD/Marshmallow.SLDPRT
CAD/Microswitch.SLDPRT
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

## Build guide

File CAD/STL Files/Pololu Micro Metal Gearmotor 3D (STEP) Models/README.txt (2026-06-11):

Pololu Micro Metal Gearmotor 3D (STEP) Models

File name key:

pm = precious metal brushes (LP, MP, and HP versions)
cb = carbon brushes (HPCB versions)

1000 = 1000:1 gear ratio, which has a longer gearboxes than the other gear ratios

enc-back-con = Encoder with Back Connector version
enc-side-con = Encoder with Side Connector version
ext-shaft = Extended Motor Shaft version

with-1086-bracket = gearmotor shown with Pololu item #1086 bracket (https://www.pololu.com/product/1086) and also covers #989 bracket which is the same but black (https://www.pololu.com/product/989)
with-1089-ext-bracket = gearmotor shown with Pololu item #1089 bracket (https://www.pololu.com/product/1089)

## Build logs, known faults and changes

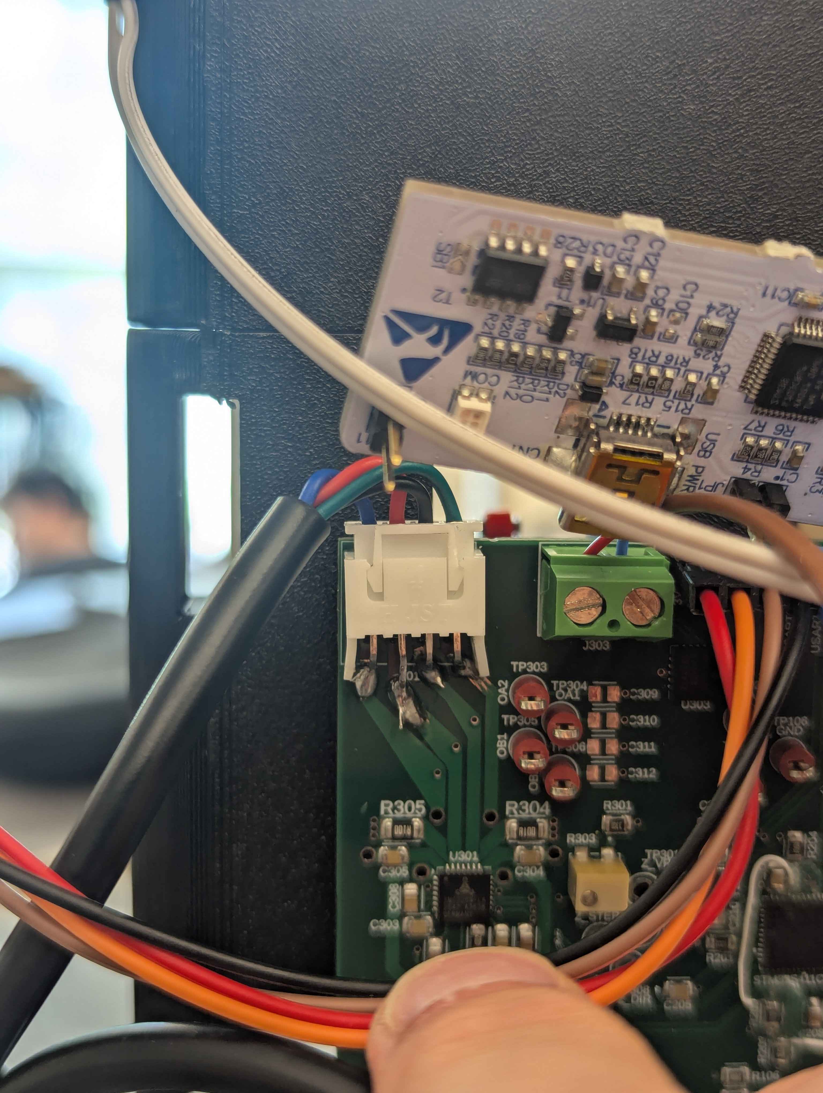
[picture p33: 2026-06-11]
docs/images/Lifted_Trace_Repair.jpg

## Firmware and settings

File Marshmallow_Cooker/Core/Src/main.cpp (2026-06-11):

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
/* Includes ------------------------------------------------------------------*/
#include "main.h"

/* USER CODE BEGIN Includes */
#include "stdio.h"
#include <cstdlib>
#include <cstring>

#if defined(__has_include)
#if __has_include("usb_device.h")
#include "usb_device.h"
#define MARSHMALLOW_HAS_USB_DEVICE 1
#endif
#if __has_include("usbd_cdc_if.h")
#include "usbd_cdc_if.h"
#define MARSHMALLOW_HAS_USB_CDC 1
#endif
#endif
#include "Task_Cooker.h"
#include "Task_R_Motor.h"
#include "Task_Temps.h"
#include "Task_UI.h"
#include "Task_Z_Motor.h"

/* USER CODE END Includes */

I2C_HandleTypeDef hi2c3;

TIM_HandleTypeDef htim1;
TIM_HandleTypeDef htim3;

UART_HandleTypeDef huart2;

/* USER CODE BEGIN PV */
TaskUI task_ui;
TaskTemps task_temps;
TaskRMotor task_r_motor;
TaskZMotor task_z_motor;
TaskCooker task_cooker(task_ui, task_temps, task_r_motor, task_z_motor);

char print_buf[100];
uint8_t print_buf_len;
/* USER CODE END PV */

void SystemClock_Config(void);
static void MX_GPIO_Init(void);
static void MX_USART2_UART_Init(void);
static void MX_I2C3_Init(void);
static void MX_TIM3_Init(void);
static void MX_TIM1_Init(void);
/* USER CODE BEGIN 0 */
void HAL_TIM_PeriodElapsedCallback(TIM_HandleTypeDef* htim) {
  (void)htim;
}

/* USER CODE END 0 */

/**
 * @brief  The application entry point.
 * @retval int
 */
int main(void) {

  /* MCU Configuration--------------------------------------------------------*/

  /* Reset of all peripherals, Initializes the Flash interface and the Systick. */
  HAL_Init();

  /* Configure the system clock */
  SystemClock_Config();

  /* Initialize all configured peripherals */
  MX_GPIO_Init();
  MX_USART2_UART_Init();
  MX_I2C3_Init();
  MX_TIM3_Init();
  MX_TIM1_Init();
#if defined(MARSHMALLOW_HAS_USB_DEVICE)
  MX_USB_DEVICE_Init();
#endif
  /* Infinite loop */
  /* USER CODE BEGIN WHILE */
  while (1) {
    /* USER CODE END WHILE */

    /* USER CODE BEGIN 3 */
    task_ui.run();
    task_temps.run();

    // Run the cooker before the motors so commands are consumed before motors update
    task_cooker.run();

    task_r_motor.run();
    task_z_motor.run();
  }
  /* USER CODE END 3 */
}

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
/* USER CODE BEGIN 4 */
// User created functions
void print_str(const char* str) {
  if (str == nullptr) {
    return;
  }

  const size_t len = std::strlen(str);

  if (len == 0U || len > UINT16_MAX) {
    return;
  }

  HAL_UART_Transmit(&huart2, reinterpret_cast<uint8_t*>(const_cast<char*>(str)), static_cast<uint16_t>(len), 100);

#if defined(MARSHMALLOW_HAS_USB_DEVICE)
  CDC_Transmit_FS(reinterpret_cast<uint8_t*>(const_cast<char*>(str)), static_cast<uint16_t>(len));
#endif
}
/* USER CODE END 4 */
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


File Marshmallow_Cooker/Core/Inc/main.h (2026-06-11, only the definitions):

#define Z_STEP_Pin GPIO_PIN_0
#define Z_STEP_GPIO_Port GPIOA
#define Z_DIR_Pin GPIO_PIN_1
#define Z_DIR_GPIO_Port GPIOA
#define Z_ENN_Pin GPIO_PIN_4
#define Z_ENN_GPIO_Port GPIOA
#define Z_DIAG_Pin GPIO_PIN_5
#define Z_DIAG_GPIO_Port GPIOA
#define BAD_SDA_Pin GPIO_PIN_6
#define BAD_SDA_GPIO_Port GPIOA
#define BAD_SCL_Pin GPIO_PIN_7
#define BAD_SCL_GPIO_Port GPIOA
#define Z_TOP_Pin GPIO_PIN_0
#define Z_TOP_GPIO_Port GPIOB
#define Z_BOT_Pin GPIO_PIN_1
#define Z_BOT_GPIO_Port GPIOB
#define R_AIN1_Pin GPIO_PIN_9
#define R_AIN1_GPIO_Port GPIOA
#define R_AIN2_Pin GPIO_PIN_10
#define R_AIN2_GPIO_Port GPIOA
#define EN_CHA_Pin GPIO_PIN_4
#define EN_CHA_GPIO_Port GPIOB
#define EN_CHB_Pin GPIO_PIN_5
#define EN_CHB_GPIO_Port GPIOB

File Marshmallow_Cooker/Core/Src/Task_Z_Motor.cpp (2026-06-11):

/**
 * @file Task_Z_Motor.cpp
 * @brief Implementation of the Z-axis motor task and PID controller.
 */

// User created includes
#include "Task_Z_Motor.h"

// Additional includes
#include <cstdio>

// Externs

TaskZMotor::TaskZMotor()
    : z_motor_driver_(),
      z_limit_switches_(Z_TOP_GPIO_Port, Z_TOP_Pin, Z_BOT_GPIO_Port, Z_BOT_Pin) {
}

void TaskZMotor::run() {
  const uint32_t now_ms = HAL_GetTick();

  if (state_ == State::Uninitialized) {
    z_motor_driver_.begin();
    z_motor_driver_.setLimitsActiveLow(false);
    z_motor_driver_.enable();
    z_motor_driver_.setSpeedStepsPerSecond(clampZMoveSpeed(kMoveSpeedStepsPerSecond));

    state_ = State::Idle;
    print_str("Z motor task initialized. Send 'home' before cooking.\r\n");
    return;
  }

  // Let the stepper driver update as often as the main loop can call this task.
  // This is what allows the speed setting to actually matter.
  z_motor_driver_.update();

  const bool task_tick_due = (now_ms - last_update_ms_) >= kUpdatePeriodMs;

  if (!task_tick_due) {
    return;
  }

  last_update_ms_ = now_ms;

  handleDriverLimitState();

  if (state_ == State::Fault) {
    z_motor_driver_.stop();
    return;
  }

  switch (state_) {
    case State::Uninitialized:
      break;

    case State::Idle:
      break;

    case State::Homing:
      if (topLimitPressed()) {
        z_motor_driver_.stop();
        z_motor_driver_.zeroPosition();
        homed_ = true;
        state_ = State::Idle;
        print_str("Z homed at top limit. Z position = 0 steps.\r\n");
      } else if (bottomLimitPressed()) {
        z_motor_driver_.stop();
        state_ = State::Fault;
        print_str("Z fault: bottom limit hit while homing upward.\r\n");
      }
      break;

    case State::MovingToStartPosition:
      if (!z_motor_driver_.isBusy()) {
        resetPid();
        state_ = State::ControllingFlameTemp;
        print_str("Z reached starting cook position. PID control active.\r\n");
      }
      break;

    case State::ControllingFlameTemp:
      if (bottomLimitPressed()) {
        z_motor_driver_.stop();
        resetPid();
        state_ = State::Idle;
        print_str("Z bottom limit reached during flame control.\r\n");
        break;
      }

      updatePidControl(now_ms);
      break;

    case State::MovingToRemovalHeight:
      if (!z_motor_driver_.isBusy()) {
        state_ = State::Idle;
        print_str("Z reached removal height.\r\n");
      }
      break;

    case State::Fault:
      break;
  }
}

void TaskZMotor::update() {
  run();
}

Task::Status TaskZMotor::getStatus() const {
  if (state_ == State::Uninitialized) {
    return Task::Status::Uninitialized;
  }

  if (state_ == State::Fault) {
    return Task::Status::Fault;
  }

  return Task::Status::Running;
}

TaskZMotor::State TaskZMotor::getState() const {
  return state_;
}

void TaskZMotor::startHoming() {
  if (state_ == State::Fault) {
    print_str("Z home rejected: task is faulted. Send reset first.\r\n");
    return;
  }

  homed_ = false;
  resetPid();

  z_motor_driver_.setSpeedStepsPerSecond(kHomeSpeedStepsPerSecond);
  z_motor_driver_.home(ZMotorDriver::Direction::Up, kHomeSpeedStepsPerSecond);

  state_ = State::Homing;
  print_str("Z homing upward toward top limit.\r\n");
}

void TaskZMotor::startTemperatureControl(int32_t target_flame_temp_fx100) {
  if (state_ == State::Fault) {
    print_str("Z temperature control rejected: task is faulted.\r\n");
    return;
  }

  if (!homed_) {
    enterFault("temperature control requested before Z home");
    return;
  }

  target_flame_temp_fx100_ = target_flame_temp_fx100;
  resetPid();
  moveToStartPosition();
}

void TaskZMotor::setMeasuredFlameTempFx100(int32_t measured_flame_temp_fx100) {
  measured_flame_temp_fx100_ = measured_flame_temp_fx100;
  valid_flame_temp_ = true;
}

void TaskZMotor::moveToRemovalHeight() {
  if (state_ == State::Fault) {
    print_str("Z removal move rejected: task is faulted.\r\n");
    return;
  }

  if (!homed_) {
    enterFault("removal height move requested before Z home");
    return;
  }

  resetPid();
  z_motor_driver_.setSpeedStepsPerSecond(clampZMoveSpeed(kMoveSpeedStepsPerSecond));
  z_motor_driver_.moveTo(kRemovalHeightSteps);
  state_ = State::MovingToRemovalHeight;
}

void TaskZMotor::moveToStartPosition() {
  if (state_ == State::Fault) {
    print_str("Z start-position move rejected: task is faulted.\r\n");
    return;
  }

  if (!homed_) {
    enterFault("start-position move requested before Z home");
    return;
  }

  z_motor_driver_.setSpeedStepsPerSecond(clampZMoveSpeed(kMoveSpeedStepsPerSecond));
  z_motor_driver_.moveTo(kStartCookingPositionSteps);
  state_ = State::MovingToStartPosition;
}

void TaskZMotor::jogRelativeSteps(int32_t relative_steps) {
  if (state_ == State::Fault) {
    print_str("Z jog rejected: task is faulted. Send reset first.\r\n");
    return;
  }

  if (!homed_) {
    print_str("Z jog rejected: home Z first.\r\n");
    return;
  }

  if (state_ == State::Homing || state_ == State::MovingToStartPosition || state_ == State::ControllingFlameTemp ||
      state_ == State::MovingToRemovalHeight || z_motor_driver_.isBusy()) {
    print_str("Z jog rejected: Z is busy.\r\n");
    return;
  }

  const int32_t current_steps = z_motor_driver_.getPositionSteps();
  int32_t target_steps = current_steps + relative_steps;

  // Do not intentionally command above home.
  if (target_steps > 0) {
    target_steps = 0;
  }

  // Do not intentionally command below the software lower travel limit.
  if (target_steps < kMinCookPositionSteps) {
    target_steps = kMinCookPositionSteps;
  }

  if (target_steps == current_steps) {
    if (relative_steps < 0) {
      print_str("Z jog down rejected: software lower limit reached.\r\n");
    } else if (relative_steps > 0) {
      print_str("Z jog up rejected: home/top limit reached.\r\n");
    } else {
      print_str("Z jog ignored: zero step request.\r\n");
    }
    return;
  }

  if (topLimitPressed() && target_steps > current_steps) {
    print_str("Z jog up rejected: top limit is pressed.\r\n");
    return;
  }

  if (bottomLimitPressed() && target_steps < current_steps) {
    print_str("Z jog down rejected: bottom limit is pressed.\r\n");
    return;
  }

  z_motor_driver_.setSpeedStepsPerSecond(clampZMoveSpeed(kMoveSpeedStepsPerSecond));
  z_motor_driver_.moveTo(target_steps);

  snprintf(print_buf,
           sizeof(print_buf),
           "Z jog: moving from %ld to %ld steps.\r\n",
           static_cast<long>(current_steps),
           static_cast<long>(target_steps));
  print_str(print_buf);
}

void TaskZMotor::stopMotion() {
  z_motor_driver_.stop();
  resetPid();

  if (state_ != State::Fault) {
    state_ = State::Idle;
  }
}

void TaskZMotor::emergencyStop() {
  z_motor_driver_.stop();
  resetPid();
  state_ = State::Fault;
  print_str("Z emergency stop. Task entered fault state.\r\n");
}
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

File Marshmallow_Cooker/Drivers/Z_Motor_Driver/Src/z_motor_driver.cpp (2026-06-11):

/**
 * @file z_motor_driver.cpp
 * @brief Implementation of the Z-axis stepper position driver.
 * @details
 *   Converts task-level relative, absolute, jog, and home commands into timed step pulses while tracking position and
 * honoring top/bottom limit switches.
 */

#include "z_motor_driver.h"

#include "main.h"
#include <climits>

ZMotorDriver::ZMotorDriver()
    : tmc_(Z_STEP_GPIO_Port,
           Z_STEP_Pin,
           Z_DIR_GPIO_Port,
           Z_DIR_Pin,
           Z_ENN_GPIO_Port,
           Z_ENN_Pin,
           Z_DIAG_GPIO_Port,
           Z_DIAG_Pin),
      position_steps_(0),
      target_steps_(0),
      speed_steps_per_second_(kDefaultSpeedStepsPerSecond),
      microsteps_(kDefaultMicrosteps),
      homing_(false),
      homing_direction_(Direction::Up),
      limits_active_low_(true),
      current_direction_(Direction::Up),
      state_(State::Disabled) {
}

void ZMotorDriver::begin() {
  tmc_.begin();
  tmc_.setStepRate(speed_steps_per_second_);
  zeroPosition();
  state_ = State::Disabled;
}

void ZMotorDriver::enable() {
  tmc_.enable();
  state_ = State::Idle;
}

void ZMotorDriver::disable() {
  tmc_.disable();
  homing_ = false;
  state_ = State::Disabled;
}

void ZMotorDriver::update() {
  if (!tmc_.isEnabled()) {
    state_ = State::Disabled;
    return;
  }

  // DIAG is currently informational only. It is logged by the TMC2209 driver,
  // but it does not stop Z motion until testing proves it is reliable.
  tmc_.updateDiagLog();

  // Hard software limit protection. If either limit switch is pressed while
  // the current motion direction would push farther into that switch, stop
  // before any more steps are issued.
  if (motionCommandActive() && topLimitPressed() && current_direction_ == Direction::Up) {
    stop();

    if (homing_direction_ == Direction::Up) {
      zeroPosition();
    }

    state_ = State::HitTopLimit;
    return;
  }

  if (motionCommandActive() && bottomLimitPressed() && current_direction_ == Direction::Down) {
    stop();

    if (homing_direction_ == Direction::Down) {
      zeroPosition();
    }

    state_ = State::HitBottomLimit;
    return;
  }

  if (homing_) {
    if (limitBlocksDirection(homing_direction_)) {
      stop();

      // For this project, homing upward defines top as Z = 0. Keeping the
      // zero here also preserves legacy homeDown behavior if it is used.
      zeroPosition();

      state_ = (homing_direction_ == Direction::Up) ? State::HitTopLimit : State::HitBottomLimit;
      return;
    }

    setDirection(homing_direction_);

    if (tryStep(homing_direction_)) {
      state_ = State::Moving;
    } else {
      state_ = State::Moving;
    }

    return;
  }

  if (position_steps_ == target_steps_) {
    state_ = State::Idle;
    return;
  }

  const Direction desired_direction = (target_steps_ > position_steps_) ? Direction::Up : Direction::Down;

  if (limitBlocksDirection(desired_direction)) {
    stop();
    state_ = (desired_direction == Direction::Up) ? State::HitTopLimit : State::HitBottomLimit;
    return;
  }

  if (tryStep(desired_direction)) {
    state_ = State::Moving;
  } else {
    state_ = State::Moving;
  }
}

void ZMotorDriver::moveSteps(int32_t steps) {
  if (steps == 0) {
    return;
  }

  homing_ = false;
  target_steps_ = position_steps_ + steps;

  if (!tmc_.isEnabled()) {
    enable();
  }

  const Direction desired_direction = (target_steps_ > position_steps_) ? Direction::Up : Direction::Down;
  setDirection(desired_direction);

  if (limitBlocksDirection(desired_direction)) {
    stop();
    state_ = (desired_direction == Direction::Up) ? State::HitTopLimit : State::HitBottomLimit;
    return;
  }

  state_ = State::Moving;
}

void ZMotorDriver::moveTo(int32_t target_position_steps) {
  homing_ = false;
  target_steps_ = target_position_steps;

  if (!tmc_.isEnabled()) {
    enable();
  }

  if (position_steps_ == target_steps_) {
    state_ = State::Idle;
    return;
  }

  const Direction desired_direction = (target_steps_ > position_steps_) ? Direction::Up : Direction::Down;
  setDirection(desired_direction);

  if (limitBlocksDirection(desired_direction)) {
    stop();
    state_ = (desired_direction == Direction::Up) ? State::HitTopLimit : State::HitBottomLimit;
    return;
  }

  state_ = State::Moving;
}

void ZMotorDriver::jog(Direction direction, uint32_t speed_steps_per_second) {
  setSpeed(speed_steps_per_second);

  if (direction == Direction::Up) {
    moveTo(INT32_MAX);
  } else {
    moveTo(INT32_MIN);
  }
}

void ZMotorDriver::stop() {
  target_steps_ = position_steps_;
  homing_ = false;

  if (tmc_.isEnabled()) {
    state_ = State::Idle;
  }
}

void ZMotorDriver::home(Direction direction, uint32_t speed_steps_per_second) {
  setSpeed(speed_steps_per_second);
  homing_direction_ = direction;
  homing_ = true;
  target_steps_ = position_steps_;

  if (!tmc_.isEnabled()) {
    enable();
  }

  setDirection(homing_direction_);

  if (limitBlocksDirection(homing_direction_)) {
    stop();
    zeroPosition();
    state_ = (homing_direction_ == Direction::Up) ? State::HitTopLimit : State::HitBottomLimit;
    return;
  }

  state_ = State::Moving;
}

void ZMotorDriver::homeUp(uint32_t speed_steps_per_second) {
  home(Direction::Up, speed_steps_per_second);
}

void ZMotorDriver::homeDown(uint32_t speed_steps_per_second) {
  home(Direction::Down, speed_steps_per_second);
}

void ZMotorDriver::zeroPosition() {
  position_steps_ = 0;
  target_steps_ = 0;
}

void ZMotorDriver::setSpeed(uint32_t steps_per_second) {
  if (steps_per_second == 0) {
    steps_per_second = 1;
  }

  speed_steps_per_second_ = steps_per_second;
  tmc_.setStepRate(speed_steps_per_second_);
}

void ZMotorDriver::setSpeedStepsPerSecond(uint32_t steps_per_second) {
  setSpeed(steps_per_second);
}

void ZMotorDriver::setMicrosteps(uint16_t microsteps) {
  if (microsteps == 0) {
    microsteps = 1;
  }

  // With the present PCB wiring, microstepping is controlled by MS1/MS2 pins.
  // This value is stored for calculations/reporting, but it cannot change the
  // TMC2209 setting.
  microsteps_ = microsteps;
}

void ZMotorDriver::setLimitsActiveLow(bool active_low) {
  limits_active_low_ = active_low;
}

void ZMotorDriver::setDirectionInverted(bool inverted) {
  tmc_.setDirectionInverted(inverted);
  setDirection(current_direction_);
}

int32_t ZMotorDriver::getPositionSteps() const {
  return position_steps_;
}

int32_t ZMotorDriver::getTargetSteps() const {
  return target_steps_;
}

ZMotorDriver::State ZMotorDriver::getState() const {
  return state_;
}

bool ZMotorDriver::isBusy() const {
  return state_ == State::Moving;
}

bool ZMotorDriver::topLimitPressed() const {
  GPIO_PinState pin_state = HAL_GPIO_ReadPin(Z_TOP_GPIO_Port, Z_TOP_Pin);
  return limits_active_low_ ? (pin_state == GPIO_PIN_RESET) : (pin_state == GPIO_PIN_SET);
}
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

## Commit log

2026-05-15 Created src and CAD folders
2026-05-20 Generated Marshmallow_Cooker STM32CubeIDE code using STM32CubeMX
2026-06-04 Updated IR Sensor to Integer x100
2026-06-04 Implementing i2c bitbanging
2026-06-06 Updated Clock for real Board
2026-06-06 working on i2c bit bang some more
2026-06-07 Motor Spins with raw HAL PWM
2026-06-08 Motor runs with motor driver. Needs clean up.
2026-06-08 Fixed Linter Issues for include paths
    [main.cpp]
2026-06-08 encoder_driver object rename
2026-06-08 Working I2C with Motors
2026-06-09 Added Preliminary MCP9600 Thermocouple Amplifier Driver
2026-06-09 Created TMC2209
    (Based on DRV8833 will be updated to current motor driver)
2026-06-09 MCP9600 reads temp wrong direction
    [MCP9600.cpp, MCP9600.h, main.cpp]
2026-06-09 Hot junctino still reading inverted
    [MCP9600.cpp, MCP9600.h, main.cpp]
2026-06-10 Uncommented IR Sensor Test Code
2026-06-10 LIMIT SWITCHES!!
2026-06-10 Limit Switches and IR Cam Test
2026-06-11 doxygen not landing on index.md
2026-06-11 Doxygen index.md landing page works!
2026-06-11 Updated z motor more and added main.h include to Task.h
2026-06-11 moved #include "stm32f4xx_hal.h" to Task.h too
2026-06-11 added read queue and integral error limit as well as some printing changes
    [Task_Cooker.cpp, Task_UI.cpp, Task_UI.h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]
2026-06-11 Implemented status and removed infinite temp printing
2026-06-11 Configured UART2 global interrupt for user inputs
2026-06-11 added duration of ir sensor back
2026-06-11 Added CAD files and CAD section to .md
    [2100-0008-0200.SLDPRT, 2100-0008-0200.STEP, 5mm-to-8mm-Connector.SLDPRT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]
2026-06-11 Updated PID done temp and duration
2026-06-11 Create Marshmallow Cooker.f3z
    [Marshmallow Cooker.f3z]
2026-06-11 Deleted extra zip file of project within git and removed empty driver folders after transitioning to src and inc

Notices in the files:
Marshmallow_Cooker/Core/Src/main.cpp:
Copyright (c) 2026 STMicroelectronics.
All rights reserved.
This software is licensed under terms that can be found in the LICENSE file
